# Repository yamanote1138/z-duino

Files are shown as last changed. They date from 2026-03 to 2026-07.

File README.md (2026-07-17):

# Z-Duino











A network-controlled Z-scale model train controller. An ESP8266 (Wemos D1 Mini) drives a TB6612FNG H-bridge motor driver, serving a webapp over WiFi that lets you control your train from any browser on the local network.

Discoverable via mDNS at `http://ztrain.local`.

## Screenshot

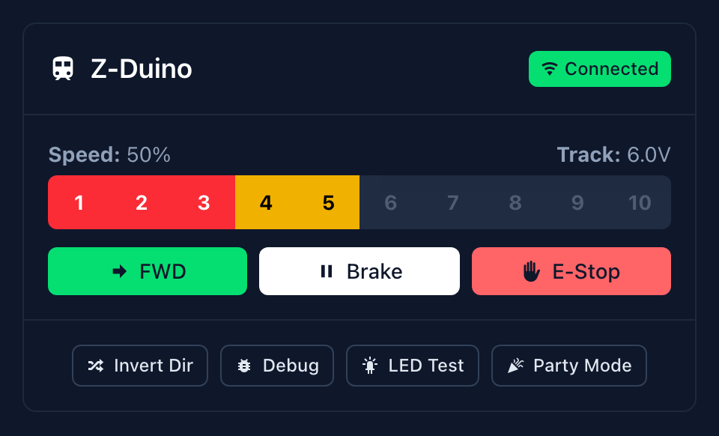
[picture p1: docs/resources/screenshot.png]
Z-Duino throttle UI


## Features

- **Throttle UI** — 10-segment speed bar with colour-coded zones (red/yellow/green), smooth ramping between speed steps
- **Direction control** — forward/reverse toggle with automatic ramp-down-switch-ramp-up when the train is moving
- **Direction invert** — swap forward/reverse polarity to match your track wiring (persisted in browser)
- **Emergency stop** — immediate halt, bypasses ramping, magenta LED blink
- **Status LED** — RGB LED indicates connection and motor state; supports manual colour control via LED test panel
- **Safety timeout** — train stops automatically if the controller loses contact for 30 seconds
- **Zero external dependencies** — everything served from the device itself, no internet required
- **mDNS discovery** — no need to remember IP addresses

## Hardware

Wemos D1 Mini (ESP8266) → TB6612FNG H-bridge → track, plus an RGB status LED. Full parts list, wiring diagram, and pinout live in **[docs/HARDWARE.md](docs/HARDWARE.md)**.

## Quickstart

1. Install [PlatformIO Core](https://docs.platformio.org/en/latest/core/installation/index.html) (`brew install platformio`) and [Node.js](https://nodejs.org/) v18+.
2. Clone the repo and configure WiFi credentials:
   ```bash
   git clone https://github.com/yamanote1138/z-duino.git
   cd z-duino
   cp secrets.ini.example secrets.ini
   # edit secrets.ini with your WiFi SSID/password
   ```
3. Install frontend dependencies and build + flash everything:
   ```bash
   cd frontend && npm install && cd ..
   ./build.sh   # select option 7 (Build + Upload All)
   ```

For the full prerequisites walkthrough and every `build.sh` option, see **[docs/BUILD.md](docs/BUILD.md)**.

## Usage

Power up the Wemos, connect your 12V track supply, and open **http://ztrain.local** in a browser (check the serial monitor at 115200 baud for the IP if mDNS doesn't resolve). Speed segments 1–10 ramp to that throttle level, FWD/REV toggles direction (ramping down/up automatically if moving), Brake ramps to a stop, and E-Stop halts immediately.

> **Z-scale note:** These locomotives are tiny and light. Don't be surprised if nothing happens at low power — it's normal for a Z-scale train to sit still until 40–50% throttle, then take off suddenly once it overcomes static friction. Start around segment 4 and work up from there.

## Documentation

- **[docs/BUILD.md](docs/BUILD.md)** — full prerequisites, setup, and `build.sh` reference
- **[docs/HARDWARE.md](docs/HARDWARE.md)** — parts list & wiring diagram
- **[docs/PROTOCOL.md](docs/PROTOCOL.md)** — WebSocket protocol spec
- **[docs/LITTLEFS.md](docs/LITTLEFS.md)** — LittleFS flash layout & partition details
- **[CONTRIBUTING.md](CONTRIBUTING.md)** — local development setup & project structure

## License

MIT

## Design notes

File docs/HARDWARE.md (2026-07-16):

# Hardware

## Parts

| Part | Purpose |
|---|---|
| Wemos D1 Mini (ESP8266) | WiFi microcontroller |
| TB6612FNG breakout | H-bridge motor driver |
| 5mm RGB LED (common cathode) | Status indicator (see [wiring](status-led-wiring.md)) |
| 12V DC power supply | Track power |
| Z-scale track + locomotive | The whole point, really |

## Wiring

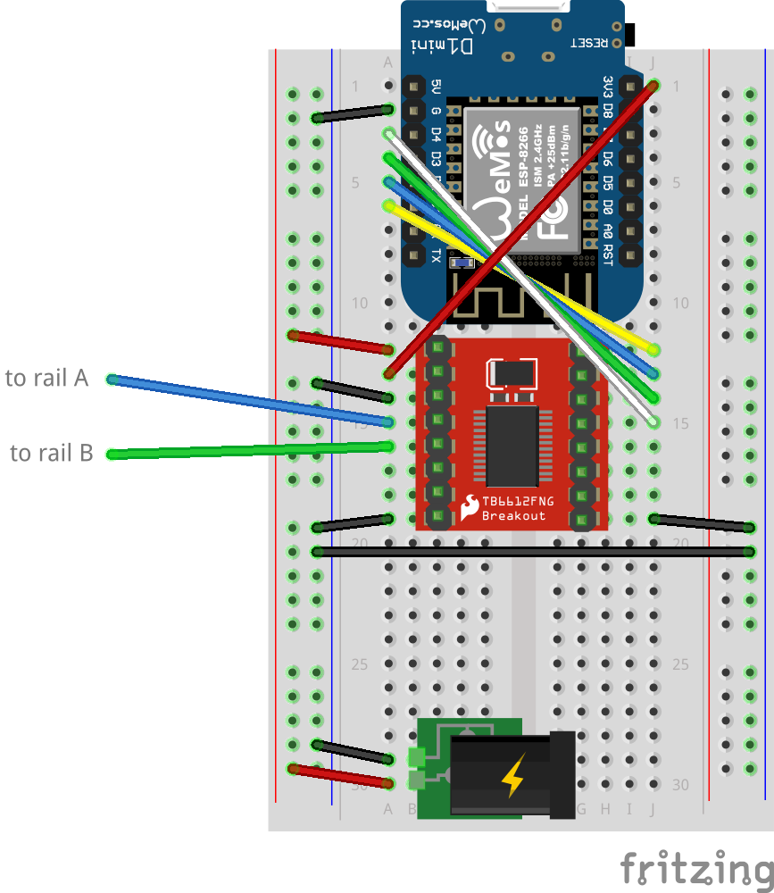
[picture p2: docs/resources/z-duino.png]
Z-Duino wiring diagram


```
Wemos D1 Mini          TB6612FNG
─────────────          ─────────
D1 (GPIO5)  ─────────  PWMA      (speed control)
D2 (GPIO4)  ─────────  AIN2      (direction pin 2)
D3 (GPIO0)  ─────────  AIN1      (direction pin 1)
D4 (GPIO2)  ─────────  STBY      (standby — active HIGH)
3.3V        ─────────  VCC       (logic power)
GND         ─────────  GND       (common ground)

12V Supply             TB6612FNG
──────────             ─────────
+12V        ─────────  VM        (motor power)
GND         ─────────  GND       (common ground)

TB6612FNG              Track
─────────              ─────
A01         ─────────  Rail 1
A02         ─────────  Rail 2
```

Only Motor A is used. Motor B pins are left unconnected.

**Status LED** — see [status-led-wiring.md](status-led-wiring.md) for full wiring, resistor values, and pinout. Summary: D5=Red (220Ω), D6=Green (100Ω), D7=Blue (100Ω), GND=Cathode.

**Important:** Connect the Wemos GND and the 12V supply GND to the TB6612FNG's GND — they must share a common ground.

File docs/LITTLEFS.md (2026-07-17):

# LittleFS & Flash Layout

How the ESP8266 filesystem works on the Wemos D1 Mini with the 4M2M flash layout, and how to avoid the pitfalls we found the hard way.

## Flash Partition Layout

`platformio.ini` sets `board_build.ldscript = eagle.flash.4m2m.ld` (the same linker script the Arduino IDE's `eesz=4M2M` board-menu option selects), which defines:

| Symbol | Value | Meaning |
|---|---|---|
| `_FS_start` | `0x40400000` | Filesystem start (memory-mapped) |
| `_FS_end` | `0x405FA000` | Filesystem end (memory-mapped) |
| `_FS_block` | `0x2000` | Block size: **8192 bytes** |
| `_FS_page` | `0x100` | Page size: **256 bytes** |

The physical flash offset is calculated by subtracting the memory map base (`0x40200000`):

```
FS_PHYS_ADDR = 0x40400000 - 0x40200000 = 0x200000
FS_PHYS_SIZE = 0x405FA000 - 0x40400000 = 0x1FA000 = 2,072,576 bytes
```

The runtime block count:

```
block_count = 2,072,576 / 8,192 = 253 (exact — no remainder)
```

## PlatformIO Handles This Automatically

As of the PlatformIO migration, `pio run -t buildfs` / `-t uploadfs` parse `_FS_START`, `_FS_END`, `_FS_BLOCK`, and `_FS_PAGE` directly out of whichever `board_build.ldscript` is configured in `platformio.ini` (currently `eagle.flash.4m2m.ld`), and pass the derived values to `mklittlefs` internally. There's no separate size constant to keep in sync — the ldscript is the single source of truth. The manual invocation below is kept for reference (e.g. if you ever need to pack an image outside of PlatformIO), but day-to-day you shouldn't need to run it by hand.

## mklittlefs Parameters (Reference)

The `mklittlefs` tool packs a directory into a LittleFS image. The parameters **must** match the runtime configuration exactly:

```bash
mklittlefs -c <source_dir> -b 8192 -p 256 -s 2072576 <output.bin>
```

| Flag | Value | Source |
|---|---|---|
| `-b` | `8192` | `_FS_block` from linker script |
| `-p` | `256` | `_FS_page` from linker script |
| `-s` | `2072576` | `_FS_end - _FS_start` = `FS_PHYS_SIZE` |

To verify an image after creation:

```bash
mklittlefs -l -b 8192 -p 256 -s 2072576 <image.bin>
```

(The `-l` flag also requires the block/page/size parameters to read the image correctly.)

## Flashing

Flash the LittleFS image to the physical offset `0x200000`:

```bash
esptool --chip esp8266 --port <PORT> --baud 460800 \
  write-flash 0x200000 littlefs.bin
```

To flash firmware and filesystem together (recommended — avoids race conditions):

```bash
esptool --chip esp8266 --port <PORT> --baud 460800 \
  write-flash 0x0 firmware.bin 0x200000 littlefs.bin
```

## The Block Count Trap

LittleFS stores `block_count` in the superblock (the metadata pair in blocks 0 and 1). During mount, the runtime compares the superblock's `block_count` against its own configured value (`FS_PHYS_SIZE / FS_PHYS_BLOCK`). If they don't match, the mount fails.

With `autoFormat` enabled (the default), a failed mount triggers a silent reformat — creating an empty filesystem with the correct block count. The result: the filesystem mounts, the firmware can create and read its own files, but every file packed into the image is gone. There are no errors, no warnings. It just... works, minus your files.

This is what happens if you use the wrong `-s` value with `mklittlefs`. For example, using `-s 2064384` (252 blocks) when the runtime expects 253 blocks. Off by one block. Silent destruction.

### How to verify

Add a temporary flash dump before `LittleFS.begin()` to inspect the raw superblock:

```cpp
uint8_t buf[64];
ESP.flashRead(0x200000, (uint32_t*)buf, 64);
// Byte 28 (little-endian uint32): block_count
// Should match FS_PHYS_SIZE / FS_PHYS_BLOCK
```

Or print the runtime values directly:

```cpp
#include "flash_hal.h"
Serial.printf("FS_PHYS_SIZE=%u FS_PHYS_BLOCK=%u block_count=%u\n",
  (uint32_t)FS_PHYS_SIZE, (uint32_t)FS_PHYS_BLOCK,
  (uint32_t)(FS_PHYS_SIZE / FS_PHYS_BLOCK));
```

## mklittlefs Version Notes

The `mklittlefs` binary bundled with the ESP8266 Arduino core (v0.2.3) bundles its own copy of the LittleFS library. The on-disk format is LittleFS v2.0 (`LFS_DISK_VERSION = 0x00020000`), which is forward-compatible with the runtime's LittleFS v2.5. The version is not the problem — the block count is.

## Other Flash Layouts

If you change `board_build.ldscript` in `platformio.ini` (e.g. to `eagle.flash.4m1m.ld` or `eagle.flash.4m3m.ld`), the values above will change accordingly. Always derive the mklittlefs parameters from the linker script for your selected layout:

```bash
# Find the linker script PlatformIO is actually using
find ~/.platformio/packages/framework-arduinoespressif8266/tools/sdk/ld -iname "*<your ldscript>*"

# Then check the values
grep '_FS_' <path_to_linker_script>
```

Or just print `FS_PHYS_SIZE` and `FS_PHYS_BLOCK` from the firmware at runtime — the definitive source of truth. (PlatformIO itself does exactly this automatically for `pio run -t buildfs`/`uploadfs` — see above.)

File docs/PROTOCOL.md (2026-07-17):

# WebSocket Protocol

The ESP8266 runs a WebSocket server on port 81 (subprotocol `arduino`).

**Client → Device:**
```json
{"cmd": "speed", "value": 0.0}                    // 0.0 to 1.0
{"cmd": "direction", "value": true}                // true = forward
{"cmd": "stop"}                                    // immediate stop
{"cmd": "ping"}                                    // keepalive
{"cmd": "invert", "value": true}                   // motor direction invert
{"cmd": "led", "r": 0, "g": 0, "b": 1000}         // LED test mode (0–1000 per channel)
{"cmd": "led_auto"}                                // resume status LED behaviour
```

**Device → Client:**
```json
{"type": "status", "name": "Z-Duino", "speed": 0.0, "direction": true, "connected": true}
{"type": "pong"}
```

The mock server (`frontend/mock-server.ts`) implements the same protocol for local development without hardware.

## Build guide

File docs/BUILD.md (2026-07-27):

# Build & Development Setup

Full software prerequisites and the `build.sh` reference. For the condensed quickstart, see the main [README](../README.md).

## Software Prerequisites

### macOS Setup

1. **PlatformIO Core** (via Homebrew):
   ```bash
   brew install platformio
   ```
   This installs `pio`, the CLI PlatformIO uses to compile, upload, and manage dependencies.

2. **Node.js** (v18+) — via [nvm](https://github.com/nvm-sh/nvm) or [nodejs.org](https://nodejs.org/):
   ```bash
   nvm install 20
   ```

That's it — the ESP8266 platform, toolchain, `mklittlefs`, `esptool`, and the `ArduinoJson`/`WebSockets` libraries are all declared in `platformio.ini` and resolved automatically the first time you run `pio run` or `./build.sh`. No separate board-package or library-install step.

### Verify Installation

```bash
pio --version   # should print version info
node --version  # v18+ required
```

## Setup

1. **Clone the repo:**
   ```bash
   git clone https://github.com/yamanote1138/z-duino.git
   cd z-duino
   ```

2. **Configure WiFi credentials:**
   ```bash
   cp secrets.ini.example secrets.ini
   ```
   Edit `secrets.ini` with your WiFi SSID and password. Optionally change the mDNS hostname (default: `ztrain`), `MAX_PWM` to tune top speed (default: `1000` — full voltage to the track), and `PWM_FREQ` to tune the motor's PWM switching frequency in Hz (default: `20000` — above the audible range, so the motor doesn't whine). `analogWrite` on the ESP8266 is software PWM sharing one hardware timer across all 4 active channels (motor + R/G/B status LED), so pushing `PWM_FREQ` too high risks starving the WiFi/WebSocket stack — the build fails outright above `40000` as a safety ceiling. These are plain PlatformIO `build_flags` (`-D WIFI_SSID='"..."'` etc. — note the single-quote wrapping, required so values with spaces survive PlatformIO's flag tokenizer) merged in via `extra_configs` in `platformio.ini` — `secrets.ini` is gitignored, so nothing here ever gets committed.

3. **Install frontend dependencies:**
   ```bash
   cd frontend
   npm install
   cd ..
   ```

4. **Build and flash:**
   ```bash
   ./build.sh
   ```
   Select option **7** (Build + Upload All). This will:
   - Build the frontend with Vite
   - Compile the firmware with PlatformIO
   - Flash the firmware to the Wemos
   - Pack and flash the frontend filesystem (LittleFS)

## Build Script Options

| Option | Action |
|---|---|
| 1 | Build All (frontend + firmware) |
| 2 | Build Frontend only |
| 3 | Build Firmware only |
| 4 | Upload Firmware only |
| 5 | Upload LittleFS only |
| 6 | Upload All (firmware + filesystem) |
| 7 | Build + Upload All |

Under the hood, `build.sh` wraps:
- **Build Frontend** (option 2) → `npm run build`, always runs unconditionally
- **Build All / Build + Upload All** (options 1, 7) → skip the frontend build automatically if nothing under `frontend/` (source, `public/`, `package.json`/`package-lock.json`, `vite.config.ts`) is newer than the existing `build/data/`, since PlatformIO's own incremental firmware compile already makes re-running `pio run` on unchanged firmware near-instant — only the frontend build previously had no such skip
- **Build Firmware** → `pio run`
- **Upload Firmware** → `pio run -t upload`
- **Upload LittleFS** → `pio run -t uploadfs` (packs `build/data/` into a LittleFS image sized from `platformio.ini`'s `board_build.ldscript`, then flashes it — see [LITTLEFS.md](LITTLEFS.md) for the partition math)

## Development

For frontend development without hardware:

```bash
cd frontend
npm run dev:all
```

This starts the Vite dev server on `http://localhost:3000` and a mock WebSocket server on port 81 that simulates the ESP8266's responses.

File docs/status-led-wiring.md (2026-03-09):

# Status LED Wiring — Z-Duino

## Component
- **Standard 4-pin through-hole RGB LED** — 5mm, **common cathode**, diffused lens

## Pin Assignments

| Wemos Pin | GPIO | LED Pin | Channel | Resistor |
|---|---|---|---|---|
| D5 | GPIO14 | Red | Red | 220Ω |
| D6 | GPIO12 | Green | Green | 100Ω |
| D7 | GPIO13 | Blue | Blue | 100Ω |
| GND | — | Cathode | Common GND | — |

## Resistor Calculations
- **Red:** (3.3V − 1.8V) / 220Ω = **6.8mA**
- **Green:** (3.3V − 3.0V) / 100Ω = **3mA**
- **Blue:** (3.3V − 3.0V) / 100Ω = **3mA**

## Wiring Diagram

```
                                    Standard 4-pin RGB LED
                                    (facing flat side of lens)
Wemos D1 Mini
┌──────────┐                        longest leg = cathode (GND)
│          │
│       D5 ├───[220Ω]──────────────── Red leg
│          │
│       D6 ├───[100Ω]──────────────── Green leg
│          │
│       D7 ├───[100Ω]──────────────── Blue leg
│          │
│      GND ├────────────────────────── Cathode (longest leg)
│          │
└──────────┘

Logic (common cathode, active HIGH):
  GPIO HIGH → LED ON  (current flows through GPIO → resistor → LED → GND)
  GPIO LOW  → LED OFF
  PWM direct: analogWrite(pin, 0)    = off
              analogWrite(pin, 1000) = full bright
```

## LED Pinout
```
Facing the flat side of the lens, legs pointing down:

  (2nd longest)  (longest)  (2nd shortest)  (shortest)
      Red        Cathode       Green          Blue

Leg lengths:  longest = GND (common cathode)
              second longest = Red
              second shortest = Green
              shortest = Blue
```

### Orientation Check
1. Find the **longest leg** — that's **Cathode (GND)**
2. Immediately left of cathode (when facing the lens): **Red**
3. Immediately right of cathode: **Green**
4. Rightmost (shortest): **Blue**

## Full Updated Pin Map

| Wemos Pin | GPIO | Function |
|---|---|---|
| D1 | GPIO5 | PWMA (motor speed) |
| D2 | GPIO4 | AIN2 (motor H-bridge) |
| D3 | GPIO0 | AIN1 (motor H-bridge) |
| D4 | GPIO2 | STBY (H-bridge enable) |
| **D5** | **GPIO14** | **Status LED — Red** |
| **D6** | **GPIO12** | **Status LED — Green** |
| **D7** | **GPIO13** | **Status LED — Blue** |
| **GND** | **—** | **Status LED — Cathode** |

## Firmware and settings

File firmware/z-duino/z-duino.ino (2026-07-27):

#include <ESP8266WiFi.h>
#include <ESP8266WebServer.h>
#include <ESP8266mDNS.h>
#include <WebSocketsServer.h>
#include <WebSockets.h>
#include <LittleFS.h>
#include <ArduinoJson.h>

#include "Motor.h"
#include "StatusLED.h"
#include <MotorLogic.h>
#include <Command.h>

#define VERSION "2.4.0"

// analogWrite on ESP8266 is software PWM sharing one hardware timer across
// all 4 active channels (motor + R/G/B status LED). Above ~40kHz the
// interrupt load starts contending with the WiFi/WebSocket stack, risking
// jitter and dropped connections.
#if PWM_FREQ > 40000
#error "PWM_FREQ exceeds the 40kHz safe ceiling for this board's shared software-PWM timer"
#endif

// WiFi credentials from secrets.ini
char wifi_ssid[] = WIFI_SSID;
char wifi_pass[] = WIFI_PASS;
char mdns_hostname[] = MDNS_HOSTNAME;
char railroad_name[] = RAILROAD_NAME;

// TB6612FNG pin assignments (Motor A only)
int pwmA = D1;   // GPIO5  - PWMA
int aIn2 = D2;   // GPIO4  - AIN2
int aIn1 = D3;   // GPIO0  - AIN1
int stby = D4;   // GPIO2  - STBY

// Status LED pin assignments (common cathode RGB)
int ledR = D5;   // GPIO14 - Red cathode
int ledG = D6;   // GPIO12 - Green cathode
int ledB = D7;   // GPIO13 - Blue cathode

// State
float currentSpeed = 0.0;
bool currentDirection = true; // true = forward
unsigned long lastMessageTime = 0;
const unsigned long SAFETY_TIMEOUT = 30000; // 30 seconds
int connectedClients = 0;
bool invertDirection = false;

// Servers
ESP8266WebServer server(80);
WebSocketsServer socket(81);

// Motor
Motor motor(pwmA, aIn1, aIn2);

// Status LED
StatusLED led(ledR, ledG, ledB);

void applyLedStatus() {
  if (connectedClients > 0) {
    led.setState(currentDirection ? ACTIVE_FORWARD : ACTIVE_REVERSE);
  } else {
    led.setState(IDLE);
  }
}

void applyMotorState() {
  MotorDecision decision = decideMotorState(currentSpeed, MAX_PWM, currentDirection, invertDirection);
  switch (decision.action) {
    case MOTOR_STOP:
      motor.stop();
      break;
    case MOTOR_FORWARD:
      motor.forward(decision.pwm);
      break;
    case MOTOR_REVERSE:
      motor.reverse(decision.pwm);
      break;
  }
}

String buildStatusJson() {
  JsonDocument doc;
  doc["type"] = "status";
  doc["name"] = railroad_name;
  doc["speed"] = currentSpeed;
  doc["direction"] = currentDirection;
  doc["connected"] = true;

  String json;
  serializeJson(doc, json);
  return json;
}

void broadcastStatus() {
  String json = buildStatusJson();
  socket.broadcastTXT(json);
}

void handleWebSocketMessage(uint8_t num, uint8_t *payload, size_t length) {
  lastMessageTime = millis();

  Command cmd = parseCommand((const char*)payload, length);

  switch (cmd.type) {
    case CMD_SPEED:
      currentSpeed = cmd.speed;
      applyMotorState();
      broadcastStatus();
      break;

    case CMD_DIRECTION:
      currentDirection = cmd.boolValue;
      applyMotorState();
      broadcastStatus();
      applyLedStatus();
      break;

    case CMD_STOP:
      currentSpeed = 0.0;
      applyMotorState();
      broadcastStatus();
      led.blinkEmergencyStop();
      break;

    case CMD_INVERT:
      invertDirection = cmd.boolValue;
      applyMotorState();
      Serial.printf("Direction invert: %s\n", invertDirection ? "on" : "off");
      break;

    case CMD_LED:
      led.setTestColor(cmd.ledR, cmd.ledG, cmd.ledB);
      Serial.printf("LED test: r=%d g=%d b=%d\n", cmd.ledR, cmd.ledG, cmd.ledB);
      break;

    case CMD_LED_AUTO:
      applyLedStatus();
      Serial.println("LED: auto status resumed");
      break;

    case CMD_PING: {
      String pong = "{\"type\":\"pong\"}";
      socket.sendTXT(num, pong);
      break;
    }

    case CMD_INVALID_JSON:
      Serial.println("JSON parse error");
      break;

    case CMD_UNKNOWN:
    default:
      break;
  }
}

void webSocketEvent(uint8_t num, WStype_t type, uint8_t *payload, size_t length) {
  switch (type) {
    case WStype_DISCONNECTED:
      Serial.printf("[%u] Disconnected\n", num);
      connectedClients--;
      if (connectedClients <= 0) {
        connectedClients = 0;
      }
      applyLedStatus();
      break;

    case WStype_CONNECTED:
      Serial.printf("[%u] Connected\n", num);
      lastMessageTime = millis();
      connectedClients++;
      applyLedStatus();
      {
        String json = buildStatusJson();
        socket.sendTXT(num, json);
      }
      break;

    case WStype_TEXT:
      handleWebSocketMessage(num, payload, length);
      break;

    default:
      break;
  }
}

void setup() {
  Serial.begin(115200);
  Serial.printf("\n\nZ-Duino v%s starting...\n", VERSION);

  // Enable STBY pin (always on)
  pinMode(stby, OUTPUT);
  digitalWrite(stby, HIGH);

  // PWM config: frequency from secrets.ini (above audible range), 0-1000 range
  analogWriteFreq(PWM_FREQ);
  analogWriteRange(1000);

  // Initialize LittleFS
  if (!LittleFS.begin()) {
    Serial.println("LittleFS mount failed");
  }

  // Connect to WiFi
  led.setState(WIFI_CONNECTING);
  WiFi.begin(wifi_ssid, wifi_pass);
  Serial.printf("Connecting to %s", wifi_ssid);
  while (WiFi.status() != WL_CONNECTED) {
    led.update();
    delay(50);
    Serial.print(".");
  }
  Serial.println();
  Serial.print("Connected! IP: ");
  Serial.println(WiFi.localIP());
  led.setState(IDLE);

  // Start mDNS
  if (MDNS.begin(mdns_hostname)) {
    Serial.printf("mDNS: http://%s.local\n", mdns_hostname);
  }

  // HTTP server: serve frontend from LittleFS
  server.on("/", HTTP_GET, []() {
    File f = LittleFS.open("/index.html", "r");
    if (!f) {
      server.send(500, "text/plain", "index.html not found on LittleFS");
      return;
    }
    server.streamFile(f, "text/html");
    f.close();
  });
  server.onNotFound([]() {
    String path = server.uri();
    if (LittleFS.exists(path)) {
      File f = LittleFS.open(path, "r");
      String contentType = "application/octet-stream";
      if (path.endsWith(".html")) contentType = "text/html";
      else if (path.endsWith(".css")) contentType = "text/css";
      else if (path.endsWith(".js")) contentType = "application/javascript";
      else if (path.endsWith(".woff2")) contentType = "font/woff2";
      server.streamFile(f, contentType);
      f.close();
    } else {
      server.send(404, "text/plain", "Not found: " + path);
    }
  });
  server.begin();
  Serial.println("HTTP server started on port 80");

  // WebSocket server
  socket.begin();
  socket.onEvent(webSocketEvent);
  Serial.println("WebSocket server started on port 81");

  lastMessageTime = millis();
}

void loop() {
  server.handleClient();
  socket.loop();
  MDNS.update();
  led.update();

  // Safety timeout: stop motor if no messages received
  if (currentSpeed > 0.0 && (millis() - lastMessageTime > SAFETY_TIMEOUT)) {
    Serial.println("Safety timeout - stopping motor");
    currentSpeed = 0.0;
    applyMotorState();
    broadcastStatus();
  }
}

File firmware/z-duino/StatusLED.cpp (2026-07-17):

#include "StatusLED.h"
#include <LedTiming.h>

StatusLED::StatusLED(int pinR, int pinG, int pinB)
  : _pinR(pinR), _pinG(pinG), _pinB(pinB), _state(WIFI_CONNECTING),
    _previousState(IDLE), _blinkCount(0), _blinkStartTime(0),
    _testR(0), _testG(0), _testB(0)
{
  pinMode(_pinR, OUTPUT);
  pinMode(_pinG, OUTPUT);
  pinMode(_pinB, OUTPUT);
  // Common cathode: 0 = fully off
  analogWrite(_pinR, 0);
  analogWrite(_pinG, 0);
  analogWrite(_pinB, 0);
}

void StatusLED::setColor(int r, int g, int b) {
  // Common cathode: value maps directly to PWM duty cycle
  // 3.3V GPIO with ~3.0V Vf on green/blue = minimal headroom, no cap needed
  analogWrite(_pinR, r);
  analogWrite(_pinG, g);
  analogWrite(_pinB, b);
}

void StatusLED::setState(LEDState state) {
  _state = state;
  switch (_state) {
    case WIFI_CONNECTING:
      // Handled in update()
      break;
    case IDLE:
      setColor(0, 0, 1000);   // Blue
      break;
    case ACTIVE_FORWARD:
      setColor(0, 1000, 0);   // Green
      break;
    case ACTIVE_REVERSE:
      setColor(1000, 0, 0);   // Red
      break;
    case LED_TEST:
      setColor(_testR, _testG, _testB);
      break;
    case EMERGENCY_STOP_BLINK:
      // Handled in update()
      break;
    default:
      break;
  }
}

void StatusLED::setTestColor(int r, int g, int b) {
  _state = LED_TEST;
  _testR = r;
  _testG = g;
  _testB = b;
  setColor(r, g, b);
}

void StatusLED::blinkEmergencyStop() {
  _previousState = _state;
  _state = EMERGENCY_STOP_BLINK;
  _blinkCount = 0;
  _blinkStartTime = millis();
}

void StatusLED::update() {
  if (_state == WIFI_CONNECTING) {
    // Sine-based breathing on red channel, ~2s cycle
    setColor(breathingBrightness(millis()), 0, 0);
  }
  else if (_state == EMERGENCY_STOP_BLINK) {
    // Blink magenta 4 times: 150ms on, 150ms off per blink
    unsigned long elapsed = millis() - _blinkStartTime;
    const unsigned long BLINK_ON = 150;
    const unsigned long BLINK_OFF = 150;
    const unsigned long BLINK_CYCLE = BLINK_ON + BLINK_OFF;
    const int TOTAL_BLINKS = 4;

    if (!isBlinkSequenceDone(elapsed, BLINK_CYCLE, TOTAL_BLINKS)) {
      if (isBlinkFrameOn(elapsed, BLINK_ON, BLINK_OFF)) {
        setColor(1000, 0, 1000);  // Magenta ON
      } else {
        setColor(0, 0, 0);        // OFF
      }
    } else {
      // Blink sequence complete — restore previous state
      _state = _previousState;
      setState(_state);
    }
  }
}

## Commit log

2026-03-07 Initial release v0.1.0: Z-scale model train controller
    ESP8266 firmware with TB6612FNG motor control, WebSocket command protocol,
    mDNS discovery, and LittleFS-served Vue 3 throttle UI with 10-segment
    speed bar, smooth ramping, and safety timeout.
2026-03-08 v1.0.0: First working release
    - Fix LittleFS block count (253 blocks, not 252) — the root cause of
    invisible filesystem files on the ESP8266
    - Add configurable MAX_PWM (default 500) to limit track voltage
    - Send railroad name in WebSocket status messages; UI displays it
    in the header and browser tab
    - Improve build.sh: dependency checks, correct mklittlefs params,
    better error handling, esptool deprecation fixes
    - Add docs/LITTLEFS.md documenting the flash layout and the block
    count trap
    - Add Z-scale usage notes to README
    - Clean up firmware (remove all diagnostic code)
    [z-duino.fzz]
2026-03-08 v1.0.1: Add Fritzing wiring diagram to README
    Include PNG export of Fritzing diagram in the wiring section,
    update corrected Fritzing source file.
    [z-duino.fzz]
2026-03-09 Add status LED, LED test panel, and direction invert
    - StatusLED class (common cathode RGB) with states: WiFi connecting
    (red breathing), idle (blue), forward (green), reverse (red), test
    - LED test panel in frontend with color buttons, bright/dim toggle,
    mutually exclusive with throttle controls
    - Direction invert: firmware-side motor XOR, LED always matches UI
    - WebSocket commands: led, led_auto, invert
    - Wiring docs for 4-pin through-hole RGB LED
    [StatusLED.cpp, z-duino.ino]
2026-03-15 v1.1.0: Add magenta blink on emergency stop
    Status LED now blinks magenta 4 times when emergency stop is triggered.
    - Added EMERGENCY_STOP_BLINK state to StatusLED
    - Implemented 4-blink sequence: 150ms on, 150ms off per blink
    - Automatically restores previous LED state after sequence completes
    - Triggered when WebSocket stop command received
2026-03-16 Migrate frontend from Bootstrap 5 to Nuxt UI + TypeScript
    - Replace Bootstrap 5 / Font Awesome with Nuxt UI (Vue plugin) + Tailwind CSS 4
    - Convert inline template + JS to SFC (App.vue) with <script setup lang="ts">
    - Extract train controller logic into useTrainController composable (singleton)
    - Decompose UI into components: TrainHeader, SpeedController, LedTestPanel,
    TrainFooter, DirectionInvert, DebugModal
    - Replace Font Awesome icons with MDI + Heroicons via Iconify bundled SVGs
    - Add debug info modal with connection, train state, and environment diagnostics
    - Add calculated track voltage display (12V × duty cycle)
    - Convert mock-server.js to TypeScript (tsx)
    - Add tsconfig.json, env.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
2026-03-16 v2.0.0: Migrate frontend to Nuxt UI + TypeScript
    Rewrote the frontend from Bootstrap 5 / Options API / vanilla JS to
    Nuxt UI + Tailwind CSS v4 + Vue 3 Composition API + TypeScript SFCs.
    Updated all documentation to reflect the new architecture, added
    concrete macOS setup instructions, and documented the full WebSocket
    protocol including LED and direction invert commands.
    [z-duino.ino]
2026-03-20 v2.1.0: Add party mode for status LED
2026-07-16 Add CI, Dependabot, and lockfile for reproducible builds
    Sets up GitHub Actions to build the frontend and compile the firmware
    on every push/PR to main, and Dependabot to track npm (frontend) and
    GitHub Actions dependency updates. Commits the frontend lockfile so
    CI and Dependabot resolve exact versions.
2026-07-16 Clean up README: badges, screenshot, split hardware docs
    Adds CI and tech-stack badges, a screenshot of the throttle UI, and
    moves the parts list and wiring diagram out to docs/HARDWARE.md to
    keep the top-level README focused on setup and usage. Also fixes a
    stale clone URL.
2026-07-17 Fix dark mode not actually applying
    Two compounding bugs made the app's forced-dark UI render in light
    mode whenever the browser's own colour-scheme preference was light:
    1. Tailwind v4 defaults dark: to a prefers-color-scheme media query,
    not a class strategy, so the static class="dark" on <html> in
    index.html never drove any dark: utility.
    2. Nuxt UI's Vite plugin defaults colorMode to true, which installs
    a @vueuse/core useDark() plugin that actively syncs <html class>
    to system preference / localStorage on mount — overwriting the
    static class="dark" the instant Vue mounted.
    Adding the class-based @custom-variant and disabling Nuxt UI's
    color-mode plugin (this UI has no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
2026-07-17 Migrate firmware build to PlatformIO, restructure docs (#8)
    * Migrate firmware build to PlatformIO, restructure docs
    Replaces arduino-cli/mklittlefs/esptool with PlatformIO across build.sh
    and CI. PlatformIO parses the FS partition geometry directly from
    board_build.ldscript (eagle.flash.4m2m.ld) on every build, removing the
    hand-maintained mklittlefs size constant that caused a silent LittleFS
    reformat bug in the past (see docs/LITTLEFS.md).
    Also splits the README into a front page with a condensed quickstart,
    moving the full prerequisites/build-script reference to docs/BUILD.md
    and the WebSocket protocol spec to docs/PROTOCOL.md.
    Bumps version to 2.3.0.
    * Lower upload_speed to 460800 (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
    [StatusLED.cpp, test_led_timing.cpp, test_motor_logic.cpp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]
2026-07-27 Configurable PWM frequency, full-duty MAX_PWM default, track voltage warning (v2.4.0) (#9)
2026-10-13 v2.4.1: throttle ramps to clicked level, docs for PWM config / voltage readout / party mode (#19)
    * Bump to v2.4.1, document PWM config, track voltage readout, and party mode
    - README: add track voltage readout, party mode, configurable PWM to features; document secrets.ini settings in quickstart; refresh TypeScript/Vite badges
    - CONTRIBUTING: PWM frequency is now configurable, not fixed at 20kHz
    - Bump version to 2.4.1 (package.json, lockfile, firmware VERSION)
    * Throttle buttons ramp to the clicked level instead of stepping down
    Clicking a lower segment now ramps to exactly that level (previously one
    level below). Clicking the segment matching the current steady speed is a
    no-op; mid-ra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
2026-11-09 v2.5.0: beat-synced techno party mode (#25)
    Party mode now simulates a 128 BPM track on the status LED: kick pulses
    with exponential decay, white hi-hat sparkle on the off-beat, a new colour
    each bar, and a rising 16th-note fill every fourth bar. Beat logic lives in
    a pure, unit-tested partyBeat.ts; frames stream at ~20fps with duplicates
    skipped to spare the ESP8266.
